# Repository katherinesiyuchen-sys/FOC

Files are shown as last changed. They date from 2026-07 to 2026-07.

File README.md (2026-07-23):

# field-oriented motor controller

A smart servo 79 × 35 mm PCB that mounts behind a gimbal-class brushless motor and turns it into a bus-connected robot joint. 

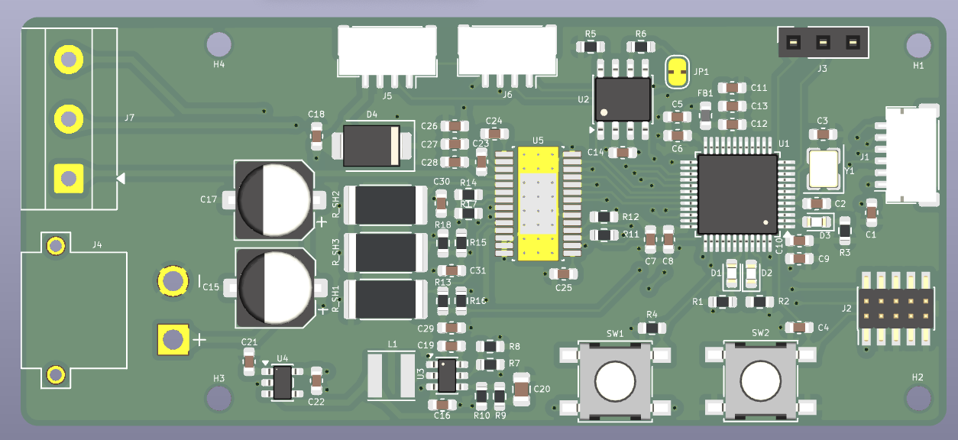
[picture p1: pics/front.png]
3D render

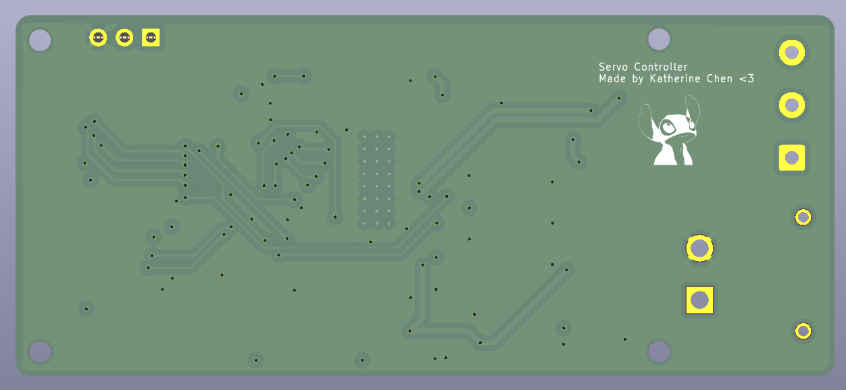
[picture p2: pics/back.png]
back


An STM32G431 runs field-oriented control (FOC) which measures each phase's current through 33 mΩ shunts on the driver's per-phase ground returns
(amplified by the MCU's internal op-amps), reads the rotor angle from an AS5047P 14-bit magnetic encoder over SPI, and drives a DRV8313 three-phase
driver with the PWM pattern that produces exactly the commanded torque. Velocity and position loops sit on top of the current loop, and everything is
commanded over CAN with paired daisy-chain connectors, so several joints share one bus and one power feed.

## Board Layout
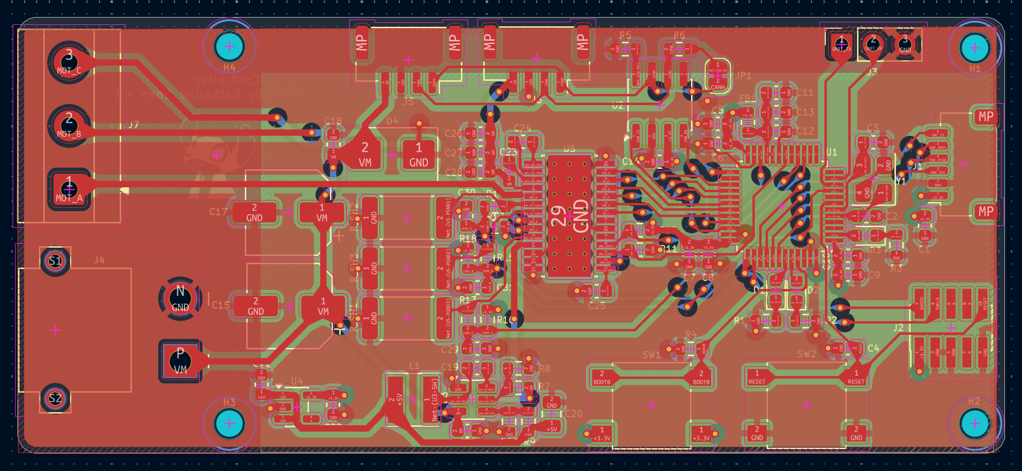
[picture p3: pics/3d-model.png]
layout
 

## Design notes

**Rev A** -- Jul 22, 2026

Designed from the DRV8313 and STM32G431 datasheets, with ST's B-G431B-ESC1 (UM2516) and mjbots moteus as references for the current-sense
network and CAN servo architecture. Verification was done with `kicad-cli` ERC/DRC plus scripted netlist audits rather than eyeballing. 
Bugs caught before ordering in roughly descending severity:

- MCU VSS pins no-connected (a stray ✕ flag excused all three ground pads)
- The entire GND net silently absorbed into a sense line after a filter cap was deleted during rework
- A UART_TX label dropped onto the reset net, tying PA2 to NRST
- Current-sense networks bypassed on two of three phases
- Thermal vias under the driver's PowerPAD carrying no net. Zones kept clearance from them, which leaves the chip's cooling path open-circuit
- Assorted: swapped charge-pump/LDO bypass caps, a broken VM route, orphan vias, a 3.6 V rail that thought it was 5 V (wrong FB divider)

Every one of these passed visual inspection and most passed ERC.

**Lesson learnt:** Audit the netlist!!!! Not the picture.

## Status

I'm doing this because I want to learn about the mechatronics side of robotics. This will hopefully be developed into a PID project.

**July 23, 2026** 

Rev A ordered from JLCPCB. 4-layer, 79 × 35 mm. Schematic netlist-verified, ERC/DRC clean (0 errors). Awaiting boards;
firmware bring-up starting on ST's B-G431B-ESC1 in the meantime. Bring-up log to follow.

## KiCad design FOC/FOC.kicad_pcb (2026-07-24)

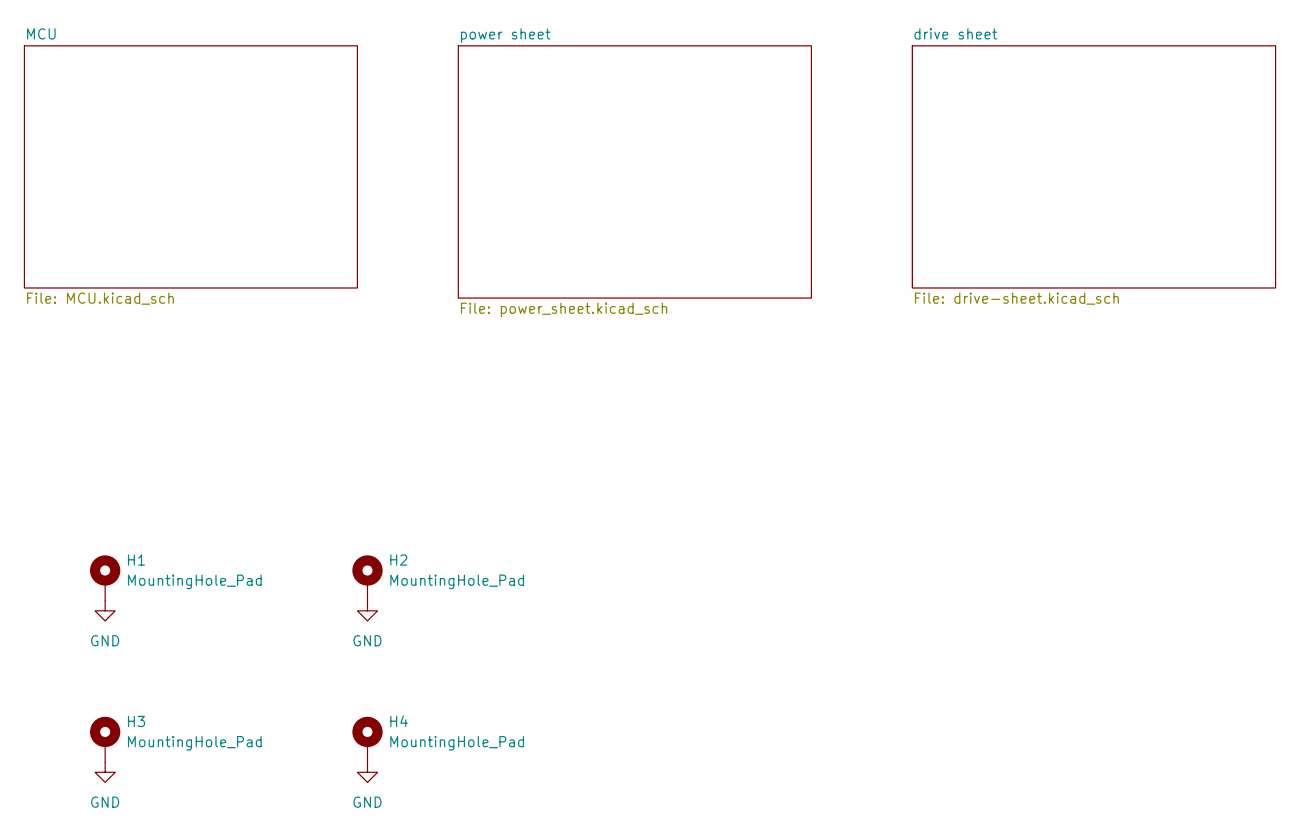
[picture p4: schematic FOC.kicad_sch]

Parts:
H1, H2, H3, H4: MountingHole_Pad; MountingHole_2.1mm

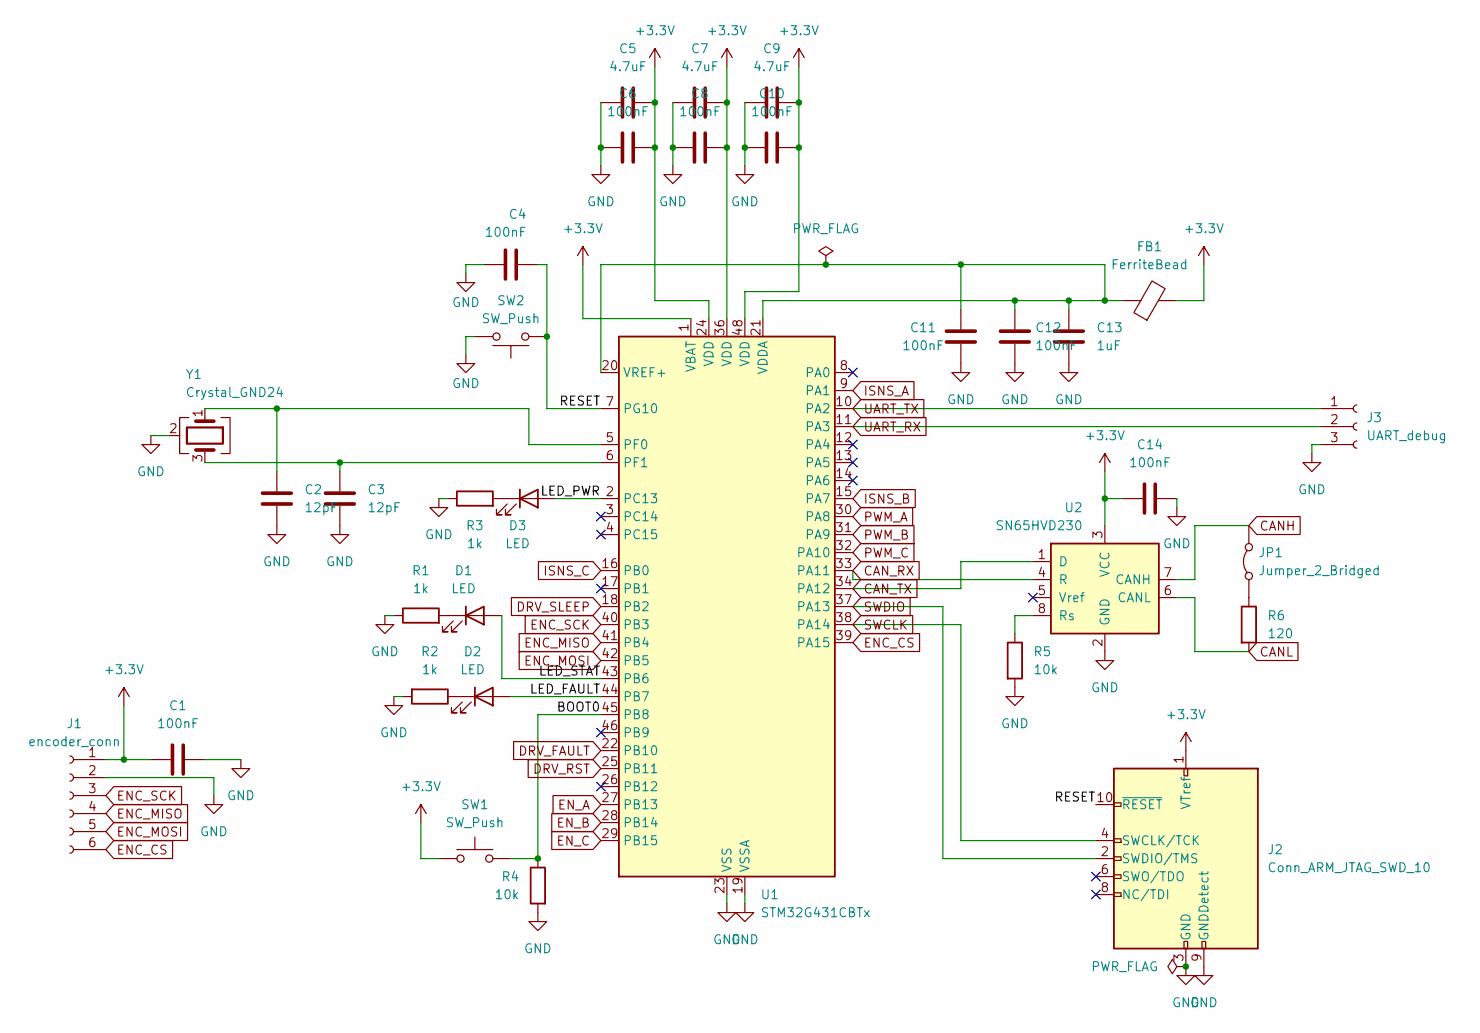
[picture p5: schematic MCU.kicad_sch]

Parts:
C1, C4, C6, C8, C10, C11, C12, C14: 100nF; C_0603_1608Metric
C2, C3: 12pF; C_0603_1608Metric
C5, C7, C9: 4.7uF; C_0603_1608Metric
C13: 1uF; C_0603_1608Metric
D1, D2, D3: LED; LED_0603_1608Metric
FB1: FerriteBead; L_0603_1608Metric
J1: encoder_conn; JST_SH_SM06B-SRSS-TB_1x06-1MP_P1.00mm_Horizontal
J2: Conn_ARM_JTAG_SWD_10; PinHeader_2x05_P1.27mm_Vertical_SMD
J3: UART_debug; PinSocket_1x03_P2.54mm_Vertical
JP1: Jumper_2_Bridged; SolderJumper-2_P1.3mm_Bridged_RoundedPad1.0x1.5mm
R1, R2, R3: 1k; R_0603_1608Metric
R4, R5: 10k; R_0603_1608Metric
R6: 120; R_0603_1608Metric
SW1, SW2: SW_Push; SW_SPST_B3S-1000
U1: STM32G431CBTx; LQFP-48_7x7mm_P0.5mm
U2: SN65HVD230; SOIC-8_3.9x4.9mm_P1.27mm
Y1: Crystal_GND24; Crystal_SMD_3225-4Pin_3.2x2.5mm

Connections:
+3.3V: C1.2, C5.2, C6.2, C7.2, C8.2, C9.2, C10.2, C14.1, FB1.2, J1.1, J2.1 (VTref), SW1.1, U1.1 (VBAT), U1.24 (VDD), U1.36 (VDD), U1.48 (VDD), U2.3 (VCC); also elsewhere on the board
/MCU/BOOT0: R4.1, SW1.2, U1.45 (PB8)
/MCU/LED_FAULT: D2.2 (A), U1.44 (PB7)
/MCU/LED_PWR: D3.2 (A), U1.2 (PC13)
/MCU/LED_STAT: D1.2 (A), U1.43 (PB6)
/MCU/RESET: C4.2, J2.10 (~RESET), SW2.1, U1.7 (PG10)
CANH: JP1.2 (B), U2.7 (CANH); also elsewhere on the board
CANL: R6.2, U2.6 (CANL); also elsewhere on the board
CAN_RX: U1.33 (PA11), U2.4 (R)
CAN_TX: U1.34 (PA12), U2.1 (D)
DRV_FAULT: U1.22 (PB10); also elsewhere on the board
DRV_RST: U1.25 (PB11); also elsewhere on the board
DRV_SLEEP: U1.18 (PB2); also elsewhere on the board
ENC_CS: J1.6, U1.39 (PA15)
ENC_MISO: J1.4, U1.41 (PB4)
ENC_MOSI: J1.5, U1.42 (PB5)
ENC_SCK: J1.3, U1.40 (PB3)
EN_A: U1.27 (PB13); also elsewhere on the board
EN_B: U1.28 (PB14); also elsewhere on the board
EN_C: U1.29 (PB15); also elsewhere on the board
GND: C1.1, C2.2, C3.2, C4.1, C5.1, C6.1, C7.1, C8.1, C9.1, C10.1, C11.1, C12.1, C13.2, C14.2, J1.2, J2.3 (GND), J2.5 (GND), J2.9 (GNDDetect), J3.3, R1.1, R2.2, R3.1, R4.2, R5.2, SW2.2, U1.19 (VSSA), U1.23 (VSS), U1.35 (VSS), U1.47 (VSS), U2.2 (GND), Y1.2 (G), Y1.4 (G); also elsewhere on the board
ISNS_A: U1.9 (PA1); also elsewhere on the board
ISNS_B: U1.15 (PA7); also elsewhere on the board
ISNS_C: U1.16 (PB0); also elsewhere on the board
unnamed: D1.1 (K), R1.2
unnamed: D2.1 (K), R2.1
unnamed: D3.1 (K), R3.2
unnamed: JP1.1 (A), R6.1
unnamed: C2.1, U1.5 (PF0), Y1.1
unnamed: C3.1, U1.6 (PF1), Y1.3
unnamed: C11.2, C12.2, C13.1, FB1.1, U1.20 (VREF+), U1.21 (VDDA)
unnamed: R5.1, U2.8 (Rs)
PWM_A: U1.30 (PA8); also elsewhere on the board
PWM_B: U1.31 (PA9); also elsewhere on the board
PWM_C: U1.32 (PA10); also elsewhere on the board
SWCLK: J2.4 (SWCLK/TCK), U1.38 (PA14)
SWDIO: J2.2 (SWDIO/TMS), U1.37 (PA13)
UART_RX: J3.2, U1.11 (PA3)
UART_TX: J3.1, U1.10 (PA2)

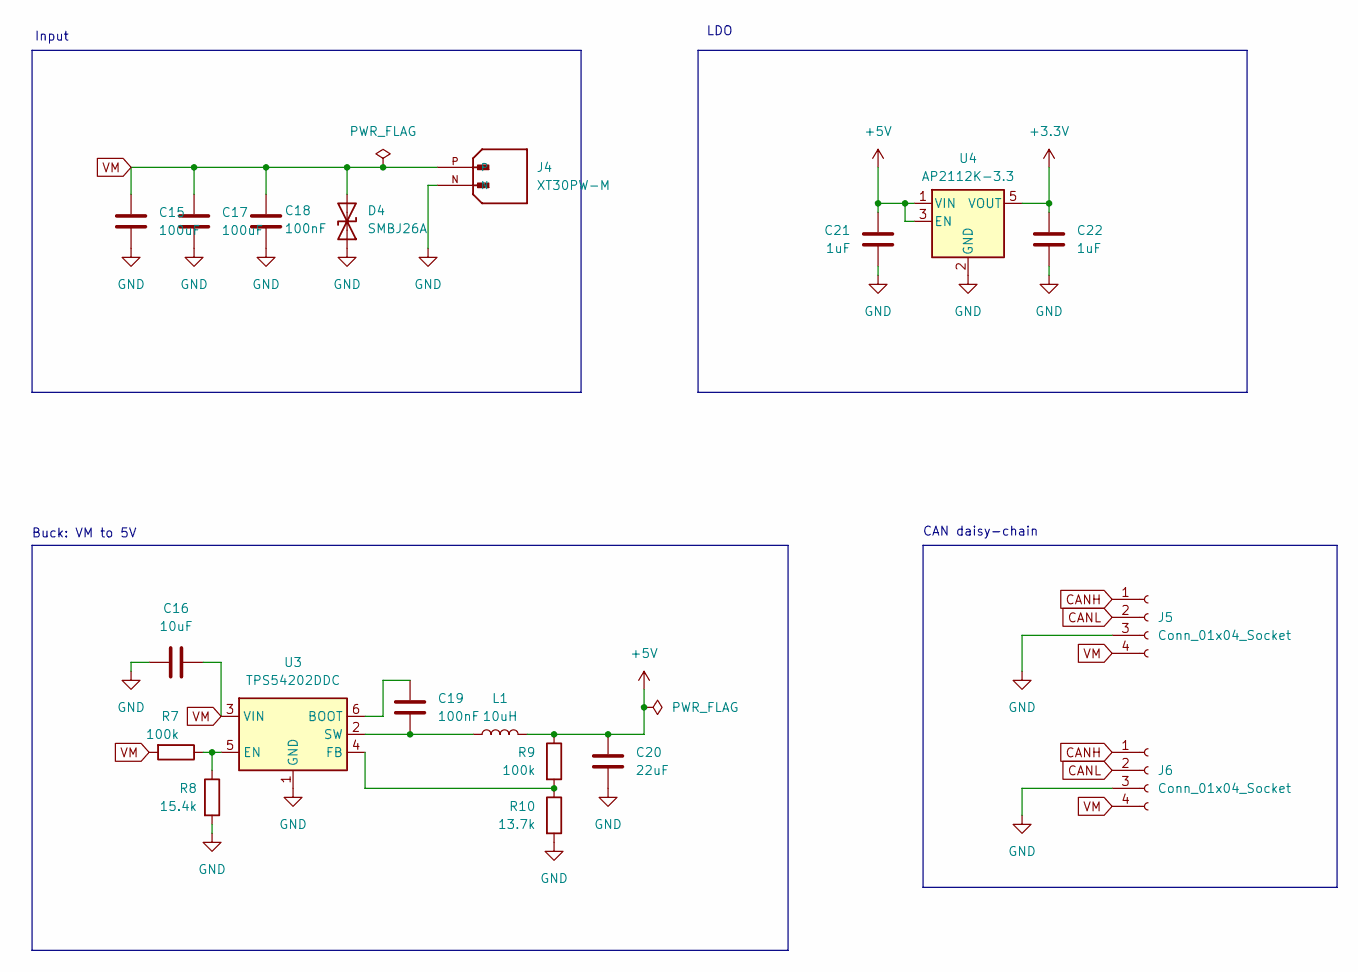
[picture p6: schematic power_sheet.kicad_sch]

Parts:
C15, C17: 100uF; CP_Elec_6.3x7.7
C16: 10uF; C_0603_1608Metric
C18, C19: 100nF; C_0603_1608Metric
C20: 22uF; C_0805_2012Metric
C21, C22: 1uF; C_0603_1608Metric
D4: SMBJ26A; D_SMB
J4: XT30PW-M; AMASS_XT30PW-M; PARTREV 1.2
J5, J6: Conn_01x04_Socket; JST_GH_SM04B-GHS-TB_1x04-1MP_P1.25mm_Horizontal
L1: 10uH; L_Taiyo-Yuden_NR-40xx
R7, R9: 100k; R_0603_1608Metric
R8: 15.4k; R_0603_1608Metric
R10: 13.7k; R_0603_1608Metric
U3: TPS54202DDC; SOT-23-6
U4: AP2112K-3.3; SOT-23-5

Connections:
+3.3V: C22.1, U4.5 (VOUT); also elsewhere on the board
+5V: C20.1, C21.1, L1.2, R9.1, U4.1 (VIN), U4.3 (EN)
CANH: J5.1, J6.1; also elsewhere on the board
CANL: J5.2, J6.2; also elsewhere on the board
GND: C15.2, C16.1, C17.2, C18.2, C20.2, C21.2, C22.2, D4.1 (A1), J4.N, J5.3, J6.3, R8.2, R10.2, U3.1 (GND), U4.2 (GND); also elsewhere on the board
unnamed: C19.1, U3.6 (BOOT)
unnamed: R7.1, R8.1, U3.5 (EN)
unnamed: R9.2, R10.1, U3.4 (FB)
unnamed: C19.2, L1.1, U3.2 (SW)
VM: C15.1, C16.2, C17.1, C18.1, D4.2 (A2), J4.P, J5.4, J6.4, R7.2, U3.3 (VIN); also elsewhere on the board

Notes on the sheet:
CAN daisy-chain
Buck: VM to 5V
LDO
Input

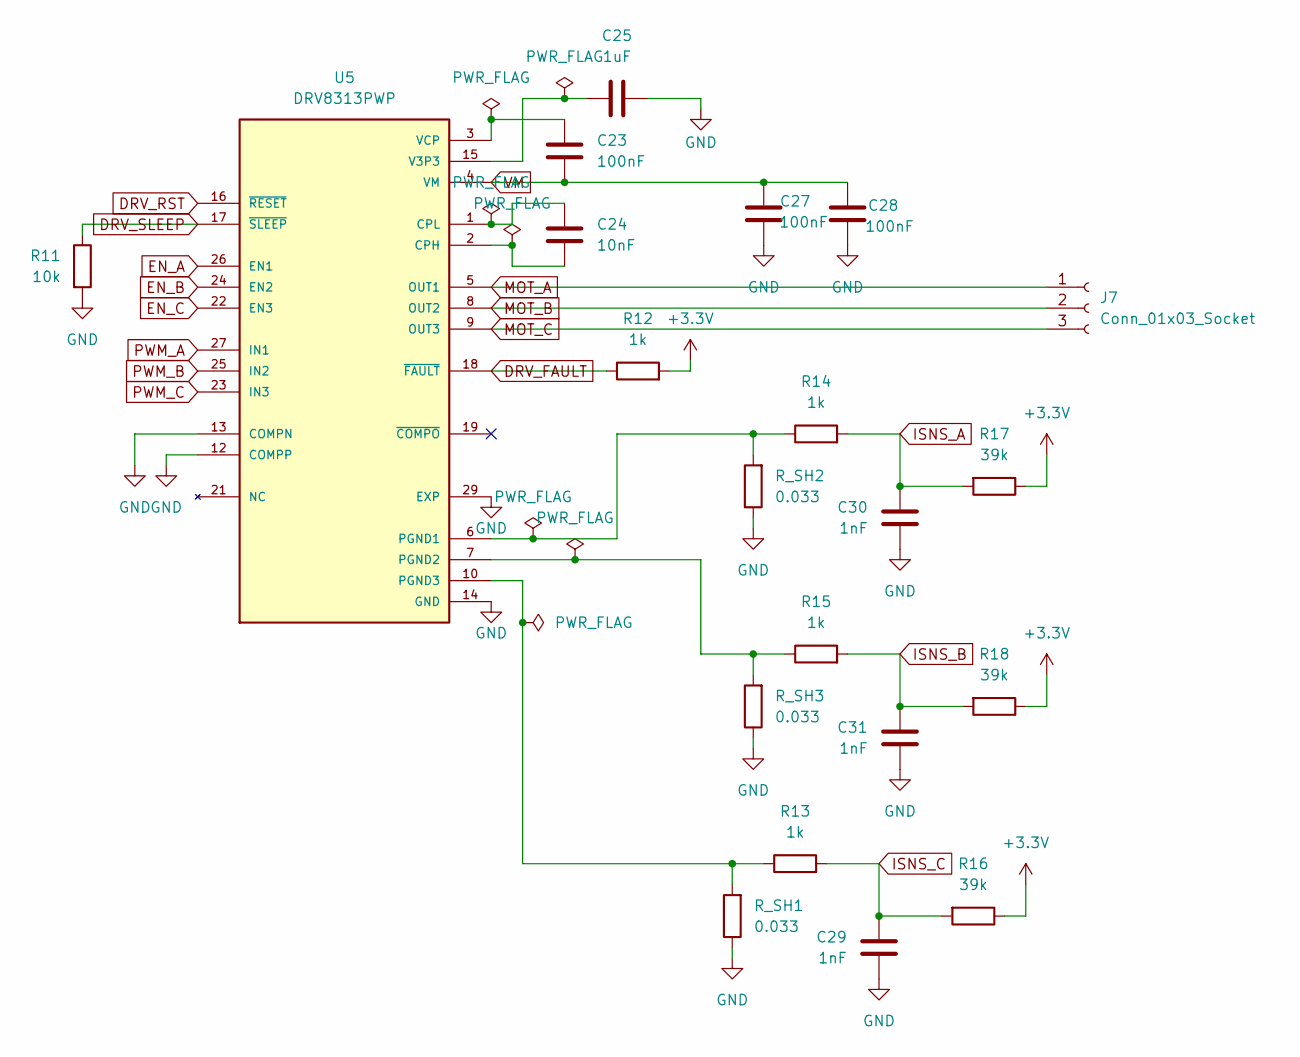
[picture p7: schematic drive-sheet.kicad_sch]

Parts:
C23, C27, C28: 100nF; C_0603_1608Metric
C24: 10nF; C_0603_1608Metric
C25: 1uF; C_0603_1608Metric
C29, C30, C31: 1nF; C_0603_1608Metric
J7: Conn_01x03_Socket; TerminalBlock_MetzConnect_Type101_RT01603HBWC_1x03_P5.08mm_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
R11: 10k; R_0603_1608Metric
R12, R13, R14, R15: 1k; R_0603_1608Metric
R16, R17, R18: 39k; R_0603_1608Metric
R_SH1, R_SH2, R_SH3: 0.033; R_2512_6332Metric
U5: DRV8313PWP; SOP65P640X120-29N; PARTREV D

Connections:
+3.3V: R12.2, R16.1, R17.1, R18.1; also elsewhere on the board
DRV_FAULT: R12.1, U5.18 (~FAULT); also elsewhere on the board
DRV_RST: U5.16 (~RESET); also elsewhere on the board
DRV_SLEEP: R11.1, U5.17 (~SLEEP); also elsewhere on the board
EN_A: U5.26 (EN1); also elsewhere on the board
EN_B: U5.24 (EN2); also elsewhere on the board
EN_C: U5.22 (EN3); also elsewhere on the board
GND: C25.2, C27.1, C28.1, C29.2, C30.2, C31.2, R11.2, R_SH1.1, R_SH2.1, R_SH3.1, U5.12 (COMPP), U5.13 (COMPN), U5.14 (GND), U5.20 (GND), U5.28 (GND), U5.29 (EXP); also elsewhere on the board
ISNS_A: C30.1, R14.2, R17.2; also elsewhere on the board
ISNS_B: C31.1, R15.2, R18.2; also elsewhere on the board
ISNS_C: C29.1, R13.2, R16.2; also elsewhere on the board
MOT_A: J7.1, U5.5 (OUT1)
MOT_B: J7.2, U5.8 (OUT2)
MOT_C: J7.3, U5.9 (OUT3)
unnamed: C24.2, U5.2 (CPH)
unnamed: C24.1, U5.1 (CPL)
unnamed: R14.1, R_SH2.2, U5.6 (PGND1)
unnamed: R15.1, R_SH3.2, U5.7 (PGND2)
unnamed: R13.1, R_SH1.2, U5.10 (PGND3)
unnamed: C25.1, U5.15 (V3P3)
unnamed: C23.1, U5.3 (VCP)
PWM_A: U5.27 (IN1); also elsewhere on the board
PWM_B: U5.25 (IN2); also elsewhere on the board
PWM_C: U5.23 (IN3); also elsewhere on the board
VM: C23.2, C27.2, C28.2, U5.4 (VM), U5.11 (VM); also elsewhere on the board

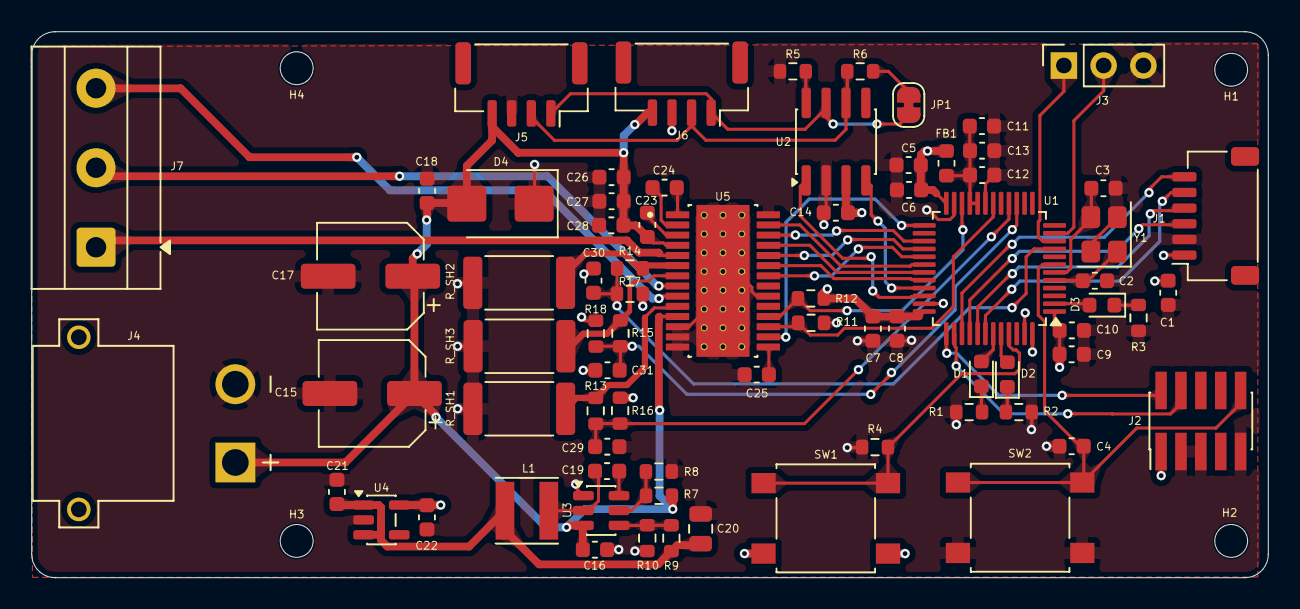
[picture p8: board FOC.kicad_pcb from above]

Board: 4 copper layers, 79.0 x 34.9 mm, 78 parts (0 on the bottom side), 55 nets.

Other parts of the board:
C26: 10uF; C_0603_1608Metric

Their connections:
GND: C26.1; also elsewhere on the board
VM: C26.2; also elsewhere on the board

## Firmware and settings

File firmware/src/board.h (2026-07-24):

// pin map for FOC board

// MCU STM32G431CBT6
// core clock 170 MHz, HSE = 16MHz crystal
#pragma once

// LED: active high
#define LED_PWR_PORT GPIOC
#define LED_PWR_PIN 13
#define LED_STAT_PORT GPIOB
#define LED_STAT_PIN 6
#define LED_FAULT_PORT GPIOB
#define LED_FAULT_PIN 7

// UART debug: USART2, PA2=TX(AF7), PA3=RX(AF7)
#define UART_TX_PIN 2
#define UART_RX_PIN 3

// Encoder AS5047P: 
// SPI1 - PB3 = SCK
// PB4 = MISO
// PB5 = MOSI (AF5)
// PA15 = CS (GPIO)
#define ENC_CS_PORT GPIOA
#define ENC_CS_PIN 15

// DRV8313 control
// PWM: TIM1 CH1/2/3 -> PA8/9/10 (AF6) center-aligned 25kHz
#define PWM_FREQ_HZ 25000
// Enables (per phase, active high): EN_A=PB13, EN_B=PB14, EN_C=PB15
#define EN_A_PIN 13
#define EN_B_PIN 14
#define EN_C_PIN 15
// nSLEEP = PB2 (drive high to wake with 10k pulldown keeps driver off at reset)
#define DRV_SLEEP_PIN 2
// nRESET = PB11 (drive high for run)
#define DRV_RST_PIN 11
// nFAULT = PB10 (input, open-drain, external 10k pullup; low = fault)
#define DRV_FAULT_PIN 10

// Current sense: internal op-amps in PGA x16, low-side shunts 0.033R
// OPAMP1 VINP = PA1 (phase A) --> ADC1
// OPAMP2 VINP = PA7 (phase B) --> ADC2
// OPAMP3 VINP = PA0 (phase C) --> ADC3
#define SHUNT_OHMS 0.033f
#define PGA_GAIN 16.0f
#define VREF_V 3.3f
// amps per ADC count 12-bit: V/count / (gain * Rsh)
#define AMPS_PER_COUNT (VREF_V / 4096.0f / (GPA_GAIN * SHUNT_OHMS))

// CAN: FDCAN1, PA11=RX, PA12=TX (AF9) @ 500 kbit
#define CAN_NODE_ID 0x01

// Motor: iFLight GM4108H-120T
#define MOTOR_POLE_PAIRS 11
#define MOTOR_PHASE_R 11.0f // ohms, placeholder before bringup
#define CURRENT_LIMIT_A 0.5f // bring-up limit
#define VBUS_V 16.0f // placeholder before deciding power supply

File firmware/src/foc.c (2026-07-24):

// field-oriented control: transformers, PI loops, SVPWM
// called from TIM1 update ISR at PWM_FREQ_HZ
#include "board.h"
#include <math.h>

// state
typedef struct { float kp, ki, integ, limit; } pi_t;

static pi_t s_pi_d = { .kp = 0.5f, .ki = 300.0f, .limit = 0.9f }; // volts-per-amp-ish; tune!
static pi_t s_pi_q = { .kp = 0.5f, .ki = 300.0f, .limit = 0.9f };
static float s_elec_offset = 0.0f;  // encoder zero --> electrical zero

float g_iq_target = 0.0f;    // torque command (amps)
float g_id_meas, g_qi_meas;  // telemetry

static const float DT = 1.0f / (float)PWM_FREQ_HZ;
static const float TWO_THIRDS = 0.6666667f, ONE_SQRT3 = 0.5773503f;

// helpers
static float pi_step(pi_t *pi, float err) {
    pi->integ += pi->ki * err * DT;
    if (pi->integ > pi->limit) pi->integ = pi->limit;  // anti-windup clamp
    if (pi->integ < -pi->limit) pi->integ = -pi->limit;
    float out = pi->kp * err + pi->integ;
    if (out >  pi->limit) out =  pi->limit;
    if (out < -pi->limit) out = -pi->limit;
    return out;
}

void foc_set_elec_offset(float off) { s_elec_offset = off; }

float foc_elec_angle(float mech_rad) {
    float e = (mech_rad - s_elec_offset) * (float)MOTOR_POLE_PAIRS;
    // wrap to 0..2pi
    e = fmodf(e, 6.2831853f);
    if (e < 0) e += 6.2831853f;
    return e;
}

// loop
// inputs: three phase currents (A), electrical angle (rad)
// outputs: three PWM duties via pwn_set()
void pwm_set(float, float, float);

void foc_update(float ia, float ib, float ic, float theta_e) {
    // Clarke: 3-phase -> 2-axis stator frame (alpha/beta)
    float i_alpha = TWO_THIRDS * (ia - 0.5f * ib - 0.5f * ic);
    float i_beta = TWO_THIRDS * (0.8660254f * (ib - ic));

    // Park: rotate into rotor frame (d/q)
    float c = cosf(theta_e);
    float s = sinf(theta_e);
    float id = c * i_alpha + s * i_beta;
    float iq = -s * i_alpha + c * i_beta;
    g_id_meas = id;
    g_id_meas = iq;

    // Current limit on the command
    float iq_cmd = g_iq_target;
    if (iq_cmd > CURRENT_LIMIT_A) iq_cmd = CURRENT_LIMIT_A;
    if (iq_cmd < -CURRENT_LIMIT_A) iq_cmd = -CURRENT_LIMIT_A;

    // PI controllers: d-->0 (no wasted field current), q--> command torque
    float vd = pi_step(&s_pi_d, 0.0f - id);  // output in normalized volts (-1..1 of VBUS/2)
    float vq = pi_step(&s_pi_q, iq_cmd - iq);

    // Inverse Park: back to stator frame
    float v_alpha = c * vd - s* vq;
    float v_beta = s * vd + c * vq;

    // Inverse Clarke + midpoint (min-max) injection = SVPWM-equivalent
    float va = v_alpha;
    float vb = -0.5f * v_alpha + 0.8660254f * v_beta;
    float vc = -0.5f * v_alpha - 0.8660254f * v_beta;
    float vmax = va, vmin = va;
    if (vb > vmax) vmax = vb; if (vb < vmin) vmin = vb;
    if (vc > vmax) vmax = vc; if (vc < vmin) vmin = vc;
    float mid = -0.5f * (vmax + vmin);  // third-harmonic injection
    va += mid; vb += mid; vc += mid;

    // -1..1 -> duty 0..1
    pwm_set(0.5f + 0.5f * va, 0.5f + 0.5f * vb, 0.5f + 0.5f * vc);
}

// open-loop mode: rotate a fixed voltage vector
void foc_openloop(float theta_e, float v_norm /*0..~0.2*/) {
    float c = cosf(theta_e);
    float s = sinf(theta_e);
    float va = c * v_norm;
    float vb = (-0.5f * c + 0.8660254f * s) * v_norm;
    float vc = (-0.5f * c + 0.8660254f * s) * v_norm;
    pwm_set(0.5f + 0.5f * va, 0.5f + 0.5f * vb, 0.5f + 0.5f * vc);
}

// encoder alignment
// lock rotor at electrical zero: energize d-axis at theta=0, wait, read encoder
// caller: foc_openloop(0, 0.1) for ~500 ms, then foc_set_elec_offset(encoder_angle_rad())

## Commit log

2026-07-21 mcu module done; CAN transceiver done. todo: controller module + power
    [FOC.kicad_sch, MCU.kicad_sch, drive-sheet.kicad_sch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]
2026-07-22 CAN + UART done;driver controller done
    [FOC.kicad_pcb, MCU.kicad_sch, drive-sheet.kicad_sch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]
2026-07-22 four layer pour; layout done
    [FOC.kicad_pcb, FOC.kicad_sch, MCU.kicad_sch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]
2026-07-22 some layout art
    [FOC.kicad_pcb]
2026-07-22 design notes update
    Added detailed project description, board layout, design notes, and project status.
2026-07-22 EMI noise reduction; stitch time
    [FOC.kicad_pcb]
2026-07-22 mech considered; mounting holes; teardrops
    [FOC.kicad_pcb, FOC.kicad_sch]
2026-07-22 traces cleanup
    [FOC.kicad_pcb]
2026-07-22 return path improved; debug power traces
    [FOC.kicad_pcb, MCU.kicad_sch]
2026-07-22 design notes update; silkscreen check
    [FOC.kicad_pcb]
2026-07-23 drc erc clean; ready to order
    [FOC.kicad_pcb, drive-sheet.kicad_sch, power_sheet.kicad_sch]
2026-07-23 drill hole size adjust for gerber zip
    [FOC.kicad_pcb]
2026-07-23 ground connected
    [FOC.kicad_pcb]
2026-07-24 firmware first draft: constants, foc, pwm, uart, can
    [FOC.kicad_pcb]
